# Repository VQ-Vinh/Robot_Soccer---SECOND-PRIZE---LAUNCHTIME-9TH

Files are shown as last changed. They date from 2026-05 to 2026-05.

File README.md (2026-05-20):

# ⚽ Robot Soccer – MLIoT_ ALICE






**Giải nhì** cuộc thi **Launchtime 9th** – Soccer robot điều khiển từ xa qua Bluetooth, sử dụng vi điều khiển STM32F103C8T6.

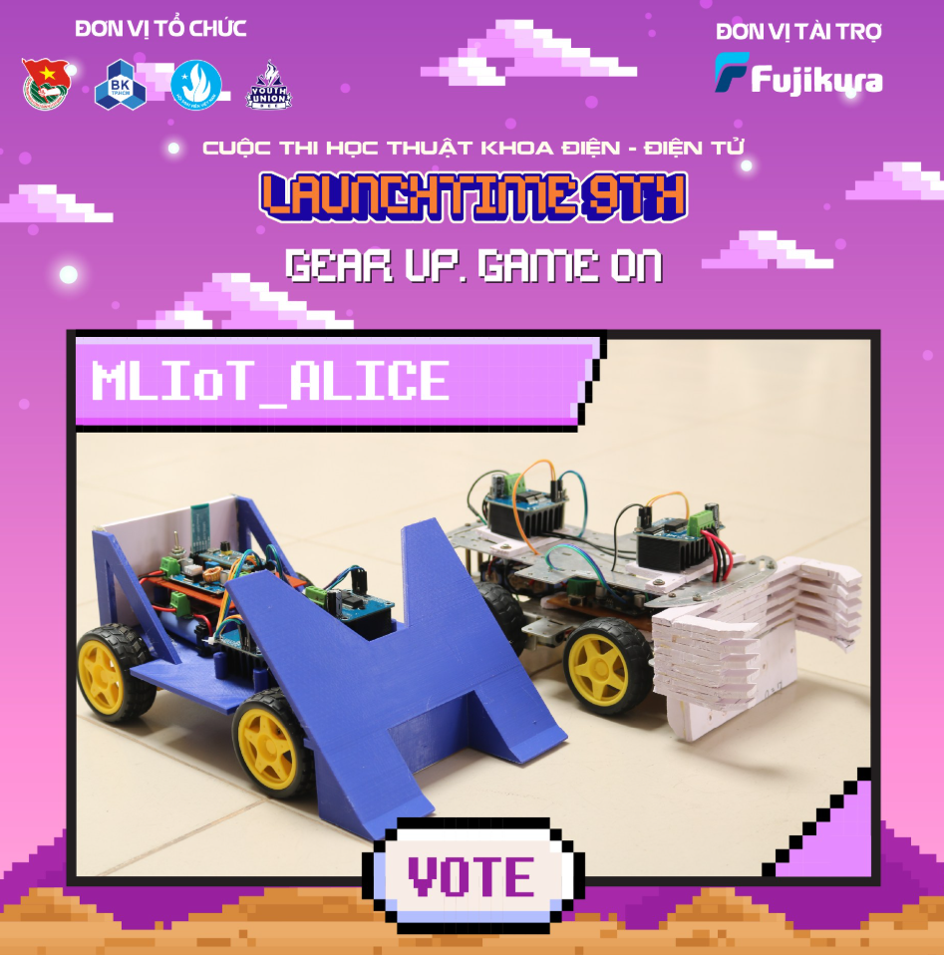
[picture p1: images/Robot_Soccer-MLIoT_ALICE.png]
Robot Soccer ALICE


---

## ✨ Tính năng / Features

- 🚗 **Điều khiển từ xa** qua Bluetooth – dùng module Bluetooth HC05
- ⚙️ **4 động cơ DC** –  với 2 driver BTS7960
- 🎛 **Điều chỉnh tốc độ** 8 mức (40%–100%)
- 🔦 **Đèn LED** trước & sau (bật/tắt)
- 📯 **Còi** (buzzer)
- ⏱ **Tự động dừng** sau 1 giây mất kết nối (safety timeout)
- 🔋 **Nguồn 12V DC**

---

## 🧱 Tổng quan phần cứng / Hardware Overview

| Linh kiện | Chi tiết |
|---|---|
| **Vi điều khiển** | STM32F103C8T6 (ARM Cortex-M3, 72 MHz) |
| **Động cơ** | 4× DC motor + 2 driver BTS7960 |
| **Giao tiếp** | USART1 (TX: PA9, RX: PA10, 9600 8N1)  |
| **Nguồn** | 12V DC |
| **Đèn** | LED trước (PB0), LED sau (PB1) |
| **Còi** | Buzzer (PB10) |
| **LED onboard** | PC13 (active low) |
| **Thạch anh** | 8 MHz HSE → PLL → 72 MHz SYSCLK |

### Sơ đồ chân / Pin Mapping

| Chân | Chức năng | Kết nối |
|---|---|---|
| PA0 | TIM2_CH1 (PWM) | Motor trái LPWM |
| PA1 | TIM2_CH2 (PWM) | Motor trái RPWM |
| PA9 | USART1_TX | Serial / Bluetooth |
| PA10 | USART1_RX | Serial / Bluetooth |
| PB0 | GPIO Output | Đèn trước |
| PB1 | GPIO Output | Đèn sau |
| PB8 | TIM4_CH3 (PWM) | Motor phải RPWM |
| PB9 | TIM4_CH4 (PWM) | Motor phải LPWM |
| PB10 | GPIO Output | Còi |
| PC13 | GPIO Output | LED onboard |

---

## 📡 Giao thức điều khiển / Control Protocol

Gửi ký tự đơn qua UART (9600 baud, 8N1).

### Di chuyển / Movement

| Lệnh | Hành động |
|---|---|
| F | Tiến |
| B | Lùi |
| L | Quay trái |
| R | Quay phải |
| G | Tiến chéo trái |
| I | Tiến chéo phải |
| H | Lùi chéo trái  |
| J | Lùi chéo phải  |
| S | Dừng |

### Tốc độ / Speed

| Lệnh | Tốc độ |
|---|---|
| 0–9  | 40–94% (40 + digit × 6) |
| q | 100% |

### Phụ kiện / Accessories

| Lệnh | Chức năng |
|---|---|
| `W` / `w` | Bật / tắt đèn trước |
| `U` / `u` | Bật / tắt đèn sau |
| `V` / `v` | Bật / tắt còi |

### ⏱ Safety Timeout

Robot tự động dừng (`S`) sau **1 giây** không nhận được lệnh để tránh mất kiểm soát trong trận đấu.

---

## 📂 Cấu trúc dự án / Project Structure

```
PUSH_GIT/
├── 3D_Design/                  # Thiết kế cơ khí (SolidWorks)
│   ├── Khungxe.SLDPRT          # Khung xe
│   ├── Asm1.SLDASM             # Lắp ráp tổng thể
│   └── *.STL                   # File in 3D (STL)
│
├── PCB_Design/                 # Thiết kế mạch điện (Altium Designer)
│   ├── Sch_ALICE.SchDoc        # Sơ đồ nguyên lý
│   ├── PCB_ALICE.PcbDoc        # Layout PCB
│   └── PCB_MLIoT_ALICE.PrjPcb  # Project Altium
│
├── SRC/                        # Firmware (STM32CubeMX + Keil)
│   ├── Core/
│   │   ├── Inc/                # Header files
│   │   └── Src/main.c          # 🧠 Chương trình chính
│   ├── Drivers/                # STM32 HAL Driver + CMSIS
│   └── MDK-ARM/
│       └── Controller_Car.uvprojx  # Keil project
│
└── images/                     # Hình ảnh tài liệu
```

---

## 🚀 Hướng dẫn build / Quick Start

### Yêu cầu / Requirements

- **IDE**: Keil uVision (MDK-ARM) v5.32+
- **Pack**: `Keil.STM32F1xx_DFP.2.4.1`
- **Toolchain**: ARM Compiler v6 (ARMCLANG)

### Build

1. Mở file project:  
   `SRC/MDK-ARM/Controller_Car.uvprojx`

2. Nhấn **Build** (F7) hoặc **Rebuild All**.

3. File `.hex` đầu ra tại:  
   `SRC/MDK-ARM/Controller_Car/Controller_Car.hex`

4. Nạp xuống STM32F103C8T6 bằng **ST-Link** hoặc **UART DFU**.

> ⚠️ Dự án được tạo từ **STM32CubeMX** (`Controller_Car.ioc`). Nếu cần thay đổi cấu hình ngoại vi, hãy mở file `.ioc` bằng CubeMX, chỉnh sửa và sinh code lại.

---

## 🖼 Thư viện ảnh / Gallery

| 3D CAD | Schematic PCB | PCB 3D View |
|---|---|---|
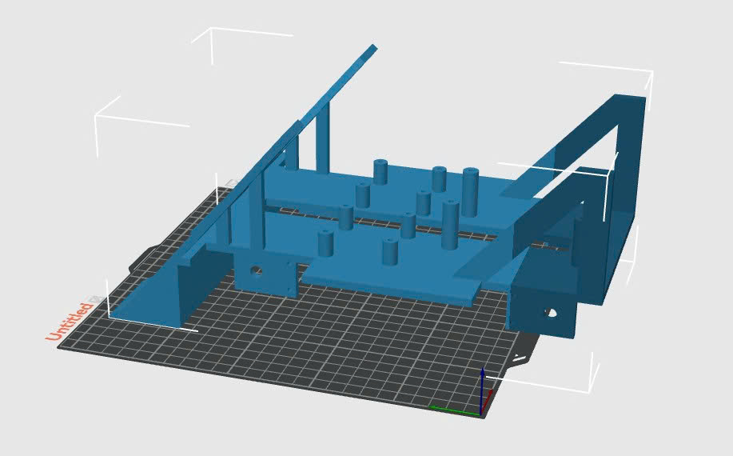
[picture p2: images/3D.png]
3D
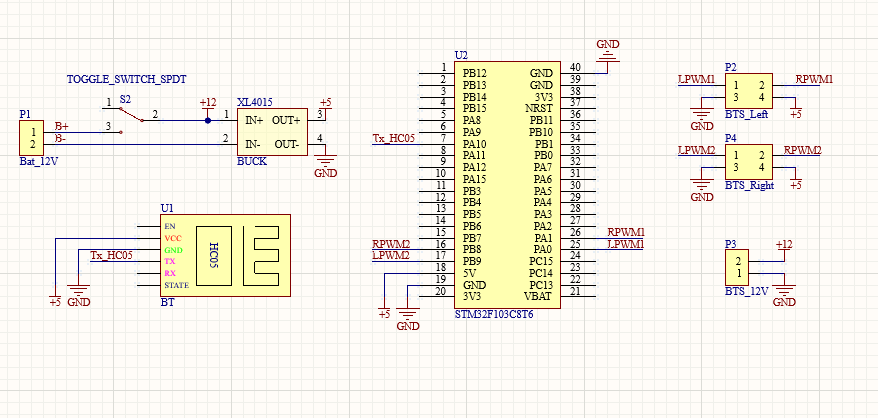
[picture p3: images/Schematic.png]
Schematic
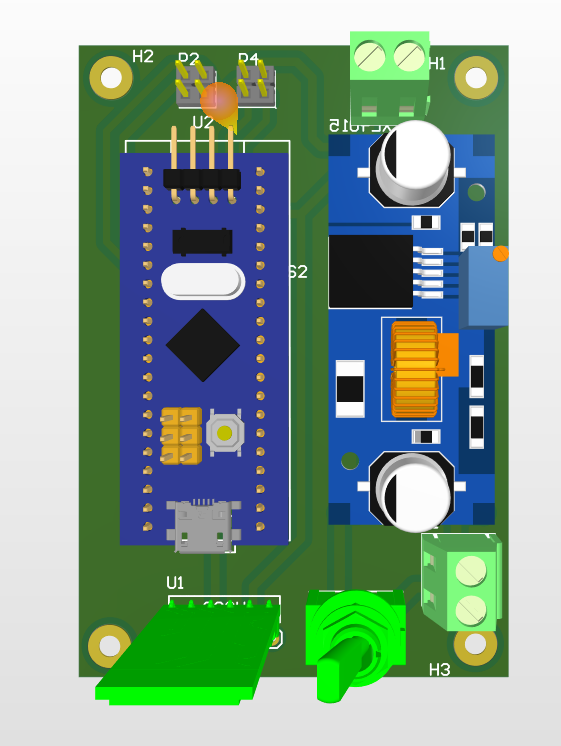
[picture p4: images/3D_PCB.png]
PCB 3D
|  |  |  |

---

## 🏆 Giải thưởng / Award

**Giải nhì – Cuộc thi Launchtime lần thứ 9**  
*Second Prize – Launchtime 9th Competition*

---

## 🛠 Công nghệ sử dụng / Built With

- [STM32CubeMX](https://www.st.com/en/development-tools/stm32cubemx.html) – MCU configuration & code generation
- [Keil MDK-ARM](https://www.keil.com/demo/eval/arm.htm) – Build & debug
- [Altium Designer](https://www.altium.com/) – PCB design
- [SolidWorks](https://www.solidworks.com/) – 3D mechanical design

---

## 📜 License

MIT License – xem file [LICENSE](LICENSE) để biết chi tiết.

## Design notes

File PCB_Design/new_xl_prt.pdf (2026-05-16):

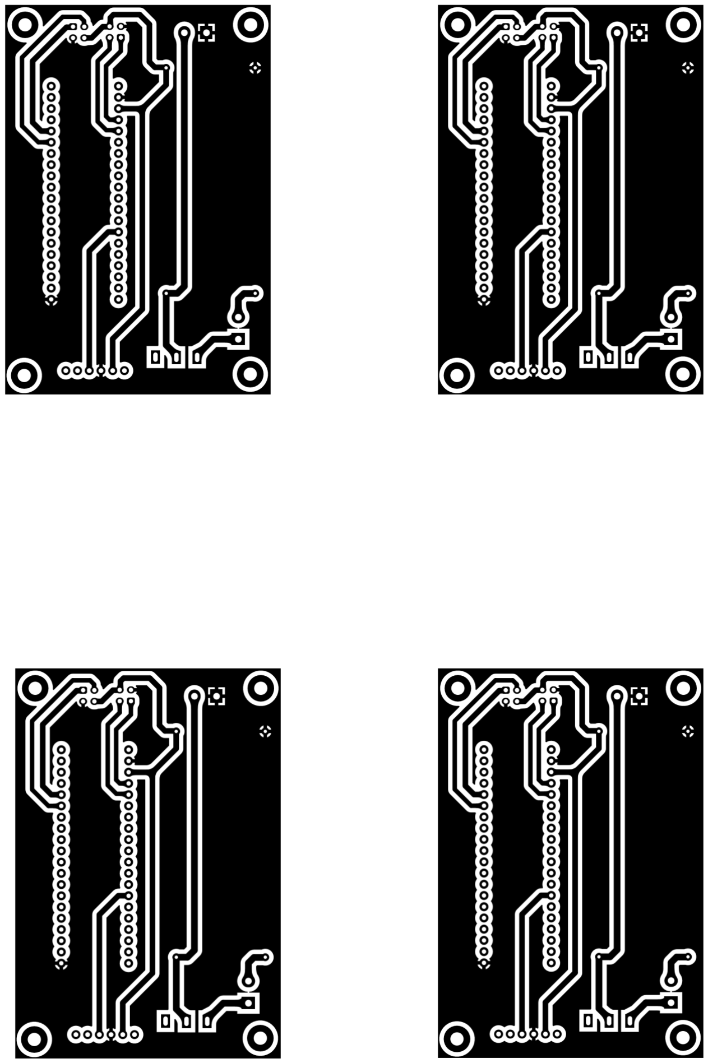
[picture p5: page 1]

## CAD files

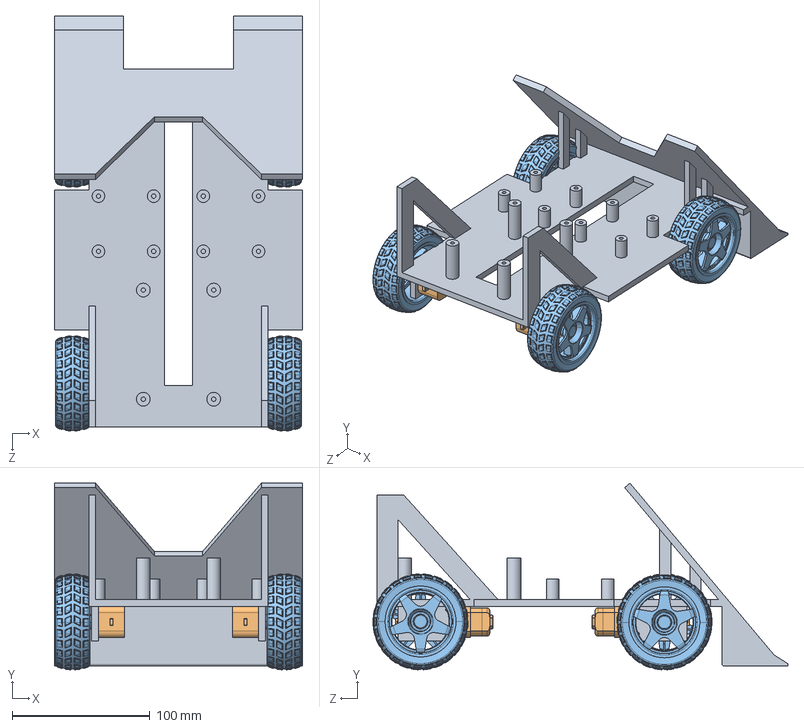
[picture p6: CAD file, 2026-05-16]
3D_Design/Asm1.SLDASM
180.0 x 135.2 x 300.7 mm
Khungxe
Gear Motor x 4
Wheelprt x 4

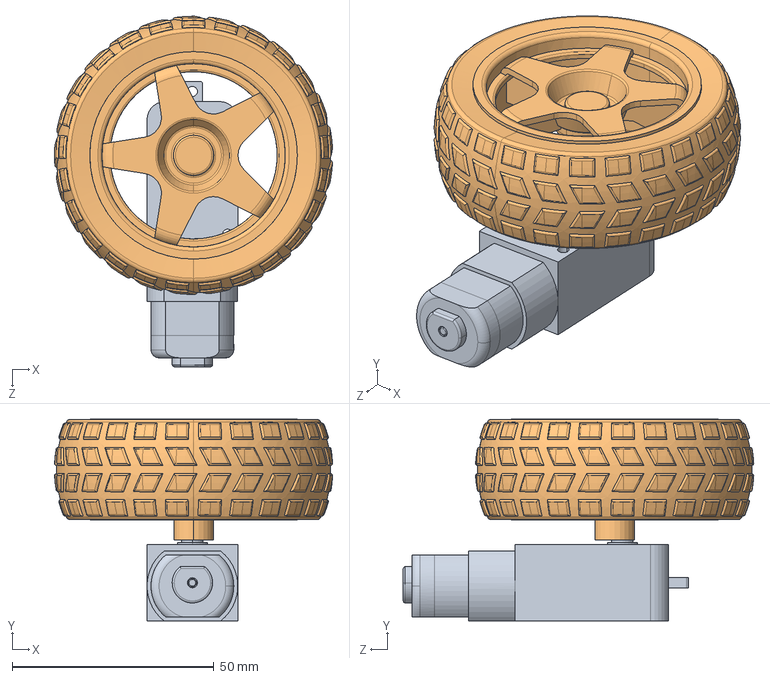
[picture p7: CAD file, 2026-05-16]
3D_Design/V1motor.SLDASM
68.9 x 50.0 x 86.8 mm
Gear Motor
Wheelprt

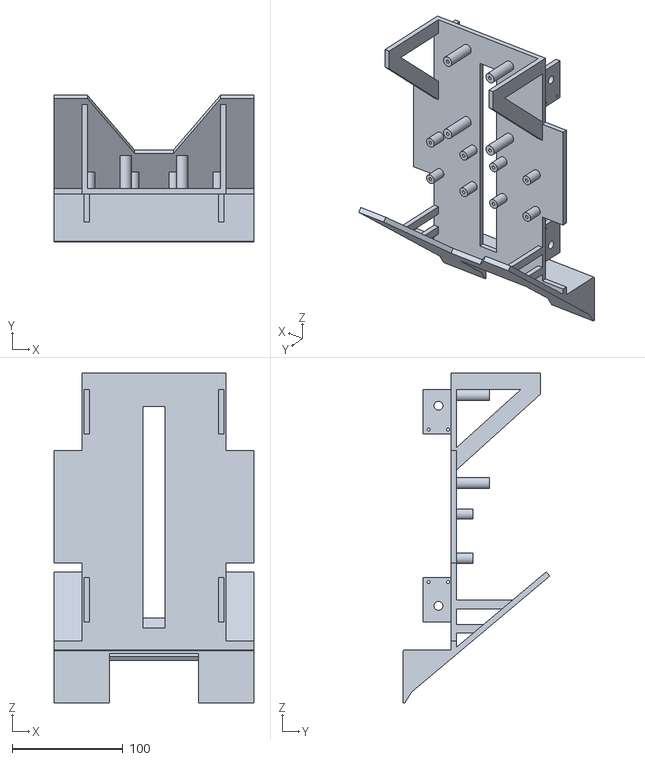
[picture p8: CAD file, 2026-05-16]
3D_Design/Khungxe1.STL
180.0 x 132.3 x 297.7

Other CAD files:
3D_Design/Khungxe.SLDPRT
3D_Design/Khungxe4mm.STL
3D_Design/Khungxe.STL

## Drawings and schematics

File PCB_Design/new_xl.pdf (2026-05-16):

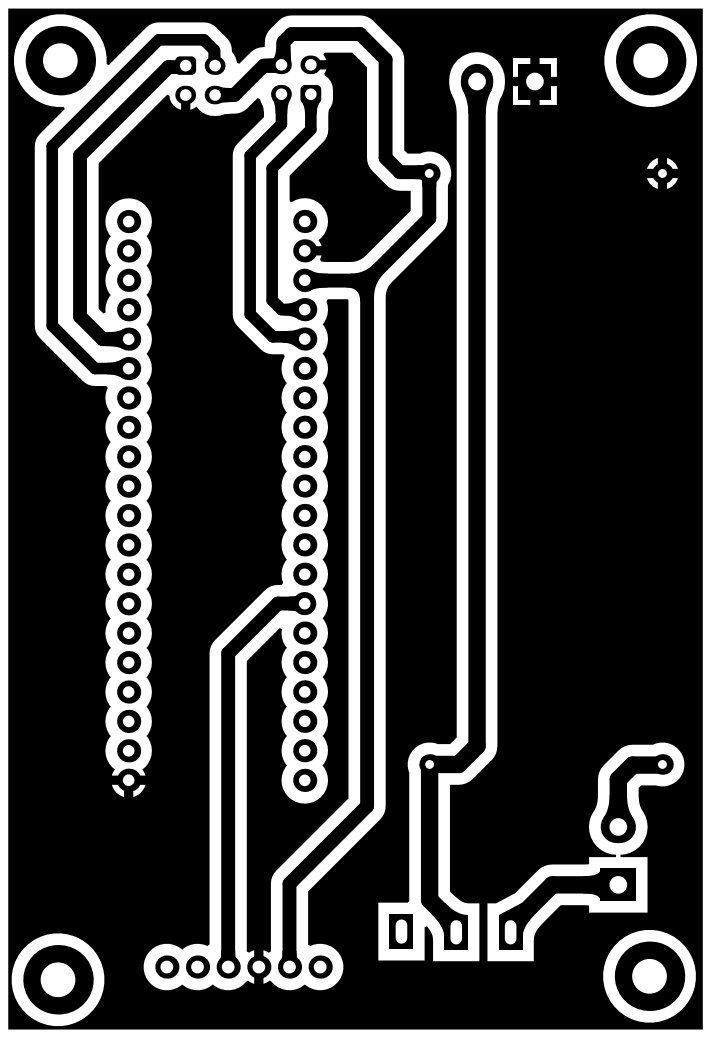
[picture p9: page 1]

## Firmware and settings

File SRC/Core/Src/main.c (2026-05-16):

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
/* Includes ------------------------------------------------------------------*/
#include "main.h"

/* USER CODE BEGIN Includes */
#include <stdlib.h>
/* USER CODE END Includes */

TIM_HandleTypeDef htim2;
TIM_HandleTypeDef htim4;

UART_HandleTypeDef huart1;

/* USER CODE BEGIN PV */
volatile uint8_t rx_data;
volatile uint8_t speed_percent = 40; // Mac dinh toc do 40%
volatile uint32_t last_command_time = 0;
#define COMMAND_TIMEOUT_MS 1000 // 1 giay timeout

/* USER CODE END PV */

void SystemClock_Config(void);
static void MX_GPIO_Init(void);
static void MX_USART1_UART_Init(void);
static void MX_TIM2_Init(void);
static void MX_TIM4_Init(void);
/* USER CODE BEGIN PFP */
void Motor_Left(int16_t speed);
void Motor_Right(int16_t speed);
uint16_t Map_PWM(uint8_t percent);

void move_forward(void);
void move_backward(void);
void turn_left(void);
void turn_right(void);
void move_forward_left(void);
void move_forward_right(void);
void move_backward_left(void);
void move_backward_right(void);
void stop_robot(void);
/* USER CODE END PFP */

/**
  * @brief  The application entry point.
  * @retval int
  */
int main(void)
{

  /* MCU Configuration--------------------------------------------------------*/

  /* Reset of all peripherals, Initializes the Flash interface and the Systick. */
  HAL_Init();

  /* Configure the system clock */
  SystemClock_Config();

  /* Initialize all configured peripherals */
  MX_GPIO_Init();
  MX_USART1_UART_Init();
  MX_TIM2_Init();
  MX_TIM4_Init();
  /* USER CODE BEGIN 2 */
	HAL_TIM_PWM_Start(&htim2, TIM_CHANNEL_1); // Left LPWM
	HAL_TIM_PWM_Start(&htim2, TIM_CHANNEL_2); // Left RPWM
	HAL_TIM_PWM_Start(&htim4, TIM_CHANNEL_3); // Right RPWM
	HAL_TIM_PWM_Start(&htim4, TIM_CHANNEL_4); // Right LPWM

	HAL_UART_Receive_IT(&huart1, (uint8_t *)&rx_data, 1);
	
	HAL_GPIO_WritePin(GPIOC, GPIO_PIN_13, GPIO_PIN_SET);
	stop_robot();
	last_command_time = HAL_GetTick(); // Khoi dong timer
  /* USER CODE END 2 */

  /* Infinite loop */
  /* USER CODE BEGIN WHILE */
  while (1)
  {
    /* USER CODE END WHILE */

    /* USER CODE BEGIN 3 */
	// Kiem tra timeout - neu khong nhan lenh trong 1s thi dung robot
	if ((HAL_GetTick() - last_command_time) > COMMAND_TIMEOUT_MS) {
		stop_robot();
	}

  }
  /* USER CODE END 3 */
}

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
/* USER CODE BEGIN 4 */
uint16_t Map_PWM(uint8_t percent) {
	if (percent > 100) percent = 100;
	return (uint16_t)((uint32_t)percent * 899 /
		100);
}

// Ham noi bo de thiet lap PWM thuc te cho dong co
void Motor_Left(int16_t speed) {
	uint16_t pwm_val = Map_PWM(abs(speed));
	if (speed >= 0) {
		__HAL_TIM_SET_COMPARE(&htim2, TIM_CHANNEL_1, 0);       // LPWM = 0
		__HAL_TIM_SET_COMPARE(&htim2, TIM_CHANNEL_2, pwm_val); // RPWM = PWM
	} else {
		__HAL_TIM_SET_COMPARE(&htim2, TIM_CHANNEL_1, pwm_val); // LPWM = PWM
		__HAL_TIM_SET_COMPARE(&htim2, TIM_CHANNEL_2, 0);       // RPWM = 0
	}
}

void Motor_Right(int16_t speed) {
	uint16_t pwm_val = Map_PWM(abs(speed));
	if (speed >= 0) {
		__HAL_TIM_SET_COMPARE(&htim4, TIM_CHANNEL_3, pwm_val); // RPWM = PWM
		__HAL_TIM_SET_COMPARE(&htim4, TIM_CHANNEL_4, 0);       // LPWM = 0
	} else {
		__HAL_TIM_SET_COMPARE(&htim4, TIM_CHANNEL_3, 0);       // RPWM = 0
		__HAL_TIM_SET_COMPARE(&htim4, TIM_CHANNEL_4, pwm_val); // LPWM = PWM
	}
}

void move_forward() { 
	Motor_Left(speed_percent);  
	Motor_Right(speed_percent); 
}

void move_backward() { 
	Motor_Left(-speed_percent); 
	Motor_Right(-speed_percent); 
}

void turn_left() {
	Motor_Left(-(speed_percent * 85) / 100); 
	Motor_Right((speed_percent * 85) / 100); 
}

void turn_right() { 
	Motor_Left((speed_percent * 85) / 100);  
	Motor_Right(-(speed_percent * 85) / 100); 
}

void move_forward_left() { 
	Motor_Left(0); 
	Motor_Right(speed_percent); 
}

void move_forward_right() { 
	Motor_Left(speed_percent);  
	Motor_Right(0); 
}

void move_backward_left() { 
	Motor_Left(0); 
	Motor_Right(-speed_percent); 
}

void move_backward_right() { 
	Motor_Left(-speed_percent); 
	Motor_Right(0); 
}

void stop_robot() {
	Motor_Left(0);
	Motor_Right(0);
}

void HAL_UART_RxCpltCallback(UART_HandleTypeDef *huart) {
	if (huart->Instance == USART1) {
		// Reset timeout khi nhan duoc lenh
		last_command_time = HAL_GetTick();

		if (rx_data >= '0' && rx_data <= '9') {
			speed_percent = 40 + (rx_data - '0') * 6; 
		} else if (rx_data == 'q') {
			speed_percent = 100;
		}

		switch (rx_data) {
			// Điều khiển di chuyển
			case 'F': move_forward(); 				break;
			case 'B': move_backward(); 				break;
			case 'L': turn_left(); 						break;
			case 'R': turn_right(); 					break;
			case 'G': move_forward_left(); 		break;
			case 'I': move_forward_right(); 	break;
			case 'H': move_backward_left(); 	break;
			case 'J': move_backward_right(); 	break;
			case 'S': stop_robot(); 					break;

			// Điều khiển LED trước (PA0)
			case 'W': HAL_GPIO_WritePin(GPIOB, GPIO_PIN_0, GPIO_PIN_SET);   break; // Bật
			case 'w': HAL_GPIO_WritePin(GPIOB, GPIO_PIN_0, GPIO_PIN_RESET); break; // Tắt

			// Điều khiển LED sau (PA1)
			case 'U': HAL_GPIO_WritePin(GPIOB, GPIO_PIN_1, GPIO_PIN_SET);   break; // Bật
			case 'u': HAL_GPIO_WritePin(GPIOB, GPIO_PIN_1, GPIO_PIN_RESET); break; // Tắt

			// Điều khiển Còi (PA2)
			case 'V': HAL_GPIO_WritePin(GPIOB, GPIO_PIN_10, GPIO_PIN_SET);   break; // Bật
			case 'v': HAL_GPIO_WritePin(GPIOB, GPIO_PIN_10, GPIO_PIN_RESET); break; // Tắt
		}
		
		// Tiếp tục nhận byte tiếp theo
		HAL_UART_Receive_IT(&huart1, (uint8_t *)&rx_data, 1);
	}
}

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


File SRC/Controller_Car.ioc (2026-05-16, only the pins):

Mcu.UserName=STM32F103C8Tx
PA0-WKUP.Signal=S_TIM2_CH1_ETR
PA1.Signal=S_TIM2_CH2
PA10.Signal=USART1_RX
PA13.Signal=SYS_JTMS-SWDIO
PA14.Signal=SYS_JTCK-SWCLK
PA9.Signal=USART1_TX
PB0.Signal=GPIO_Output
PB1.Signal=GPIO_Output
PB10.Signal=GPIO_Output
PB8.Signal=S_TIM4_CH3
PB9.Signal=S_TIM4_CH4
PC13-TAMPER-RTC.Signal=GPIO_Output
PD0-OSC_IN.Signal=RCC_OSC_IN
PD1-OSC_OUT.Signal=RCC_OSC_OUT

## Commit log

2026-05-16 Initial commit - Robot Soccer project
    [Asm1.SLDASM, Khungxe.SLDPRT, Khungxe.STL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]
2026-05-16 Add images and update README with design screenshots
    [Sch_ALICE.SchDoc]

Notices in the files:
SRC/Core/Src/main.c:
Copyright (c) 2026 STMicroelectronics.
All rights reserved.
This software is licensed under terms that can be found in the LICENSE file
